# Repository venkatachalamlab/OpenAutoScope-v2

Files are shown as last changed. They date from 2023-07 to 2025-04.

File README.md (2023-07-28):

# OpenAutoScope2.0

<div style="display: flex; justify-content: center;">
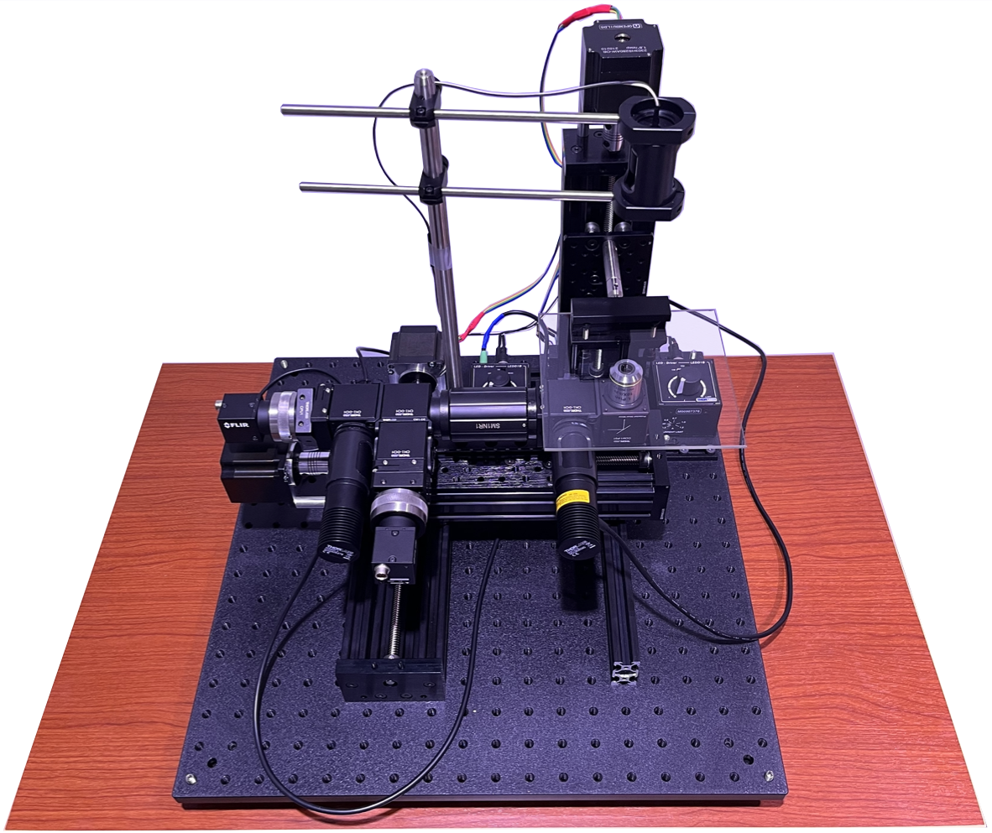
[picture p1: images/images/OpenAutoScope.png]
    
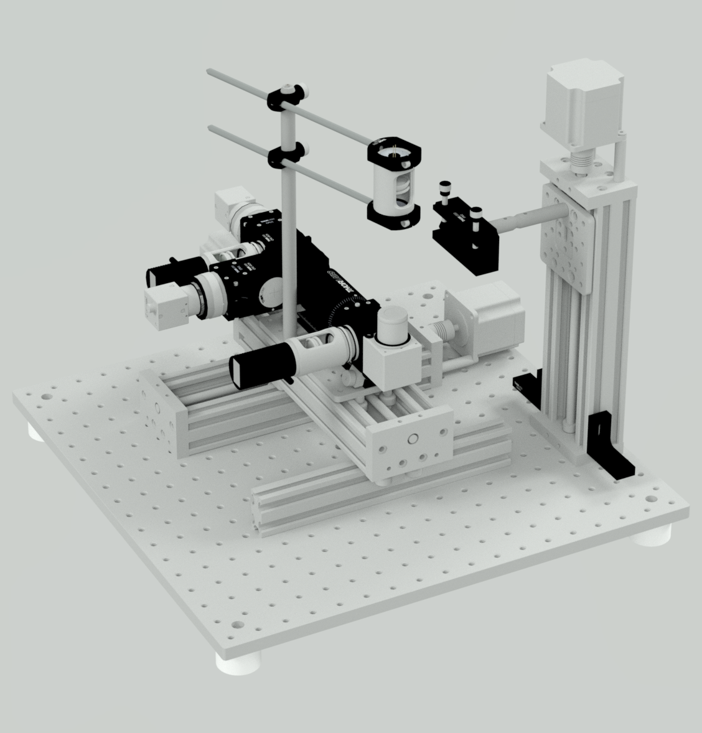
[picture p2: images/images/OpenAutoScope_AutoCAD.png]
    
</div>

# About

The OpenAutoScope is a compact dual-channel microscope engineered to enable precise tracking of single nematodes  (_C. elegans_) and facilitate optogenetic experiments. This imaging system allows recording behavior and dynamic fluorescence (e.g. GCaMP) from a small number of well-separated cells while simultaneously delivering non-targetted light stimulation.

# Hardware Design
OpenAutoScope2.0 houses optical components in a compact design, mounted on an xy motorized stage. A tracking system ensures the sample remains stationary in the xy-plane while permitting movement in the z direction. There are three distinct light paths: an IR path for behavior, a 595nm path for optogenetic stimulation, and a 470nm path for fluorescent imaging in a GFP channel. To simultaneously focus on the sample for both behavior and GFP imaging, we have included an adjustable tube lens and a separate 5mm travel range for each camera.

<p align="center">
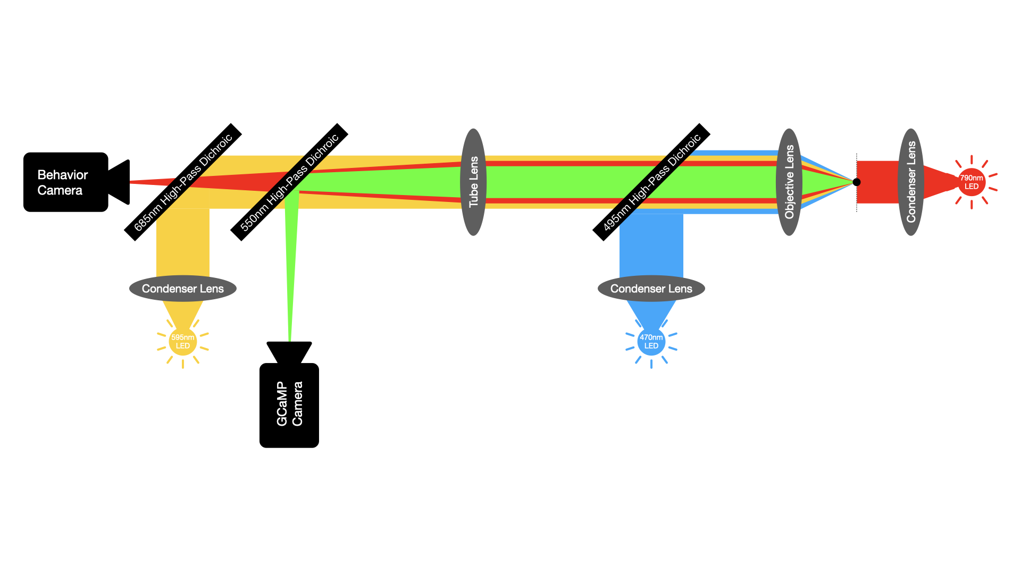
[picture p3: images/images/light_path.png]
  
</p>

# Software Design
OpenAutoScope2.0 comes with an open-source software primarily written in Python. Its architecture comprises multiple devices, each responsible for controlling a specific hardware component or performing a designated task. Communication between these devices occurs through the ZeroMQ messaging library.

The system utilizes two FLIR cameras for imaging purposes. To interface with these cameras, specific Software Development Kits (SDKs) are required. Detailed instructions for installing and configuring these SDKs are provided in the [installation](documentation/installation.md) section of the software documentation.

<p align="center">
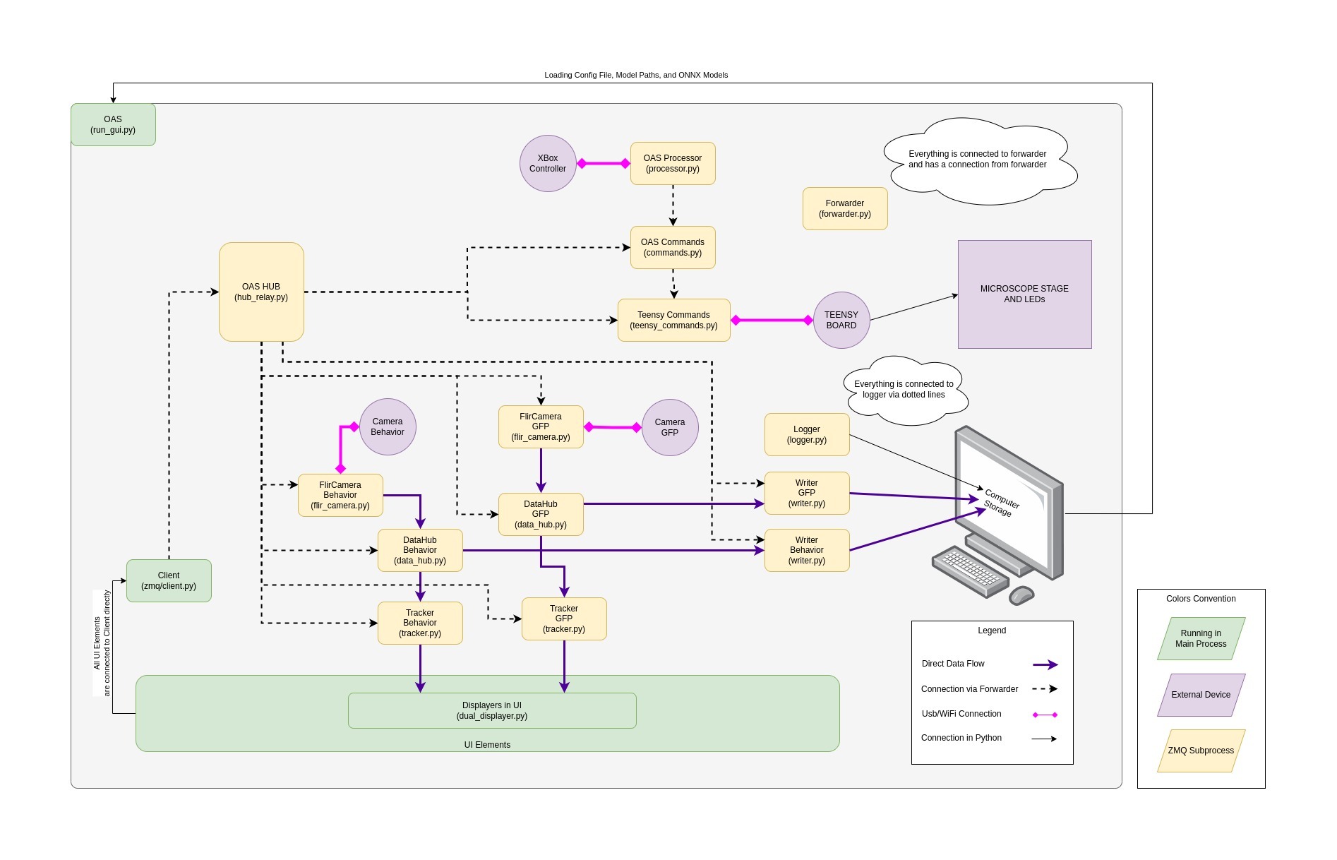
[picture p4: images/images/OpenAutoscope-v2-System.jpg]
  
</p>

# Tracker Design 
To ensure robust and accurate tracking of worms at various developmental stages, we have incorporated a customized version of the [ResNet18](https://arxiv.org/abs/1512.03385) deep CNN. This modified architecture is optimized to minimize inference time while maintaining reliability. Training the network involved utilizing a comprehensive dataset of over 17,000 annotated frames, where the terminal bulb was annotated. In Panel A of the accompanying figure, the architecture of the network is depicted, showing the changes made in the number of planes for each layer. The fully connected (FC) layer has been modified to output two coordinates, representing the y and x positions respectively. In Panel B, the histogram of squared error (SE) losses for the test data is plotted, providing insights into the performance of the network. Additionally, Panels C and D showcase images of worms at the L4 and young adult stages, respectively. In Panel C, the worm is situated on a seeded plate, while in Panel D, it is positioned between the agar pad and the glass (for detailed instructions on sample preparation, refer to [this resource](documentation/sample_preparation.md)). The annotated points are represented by red dots, while the blue circles correspond to the output generated by the trained network.

<p align="center">
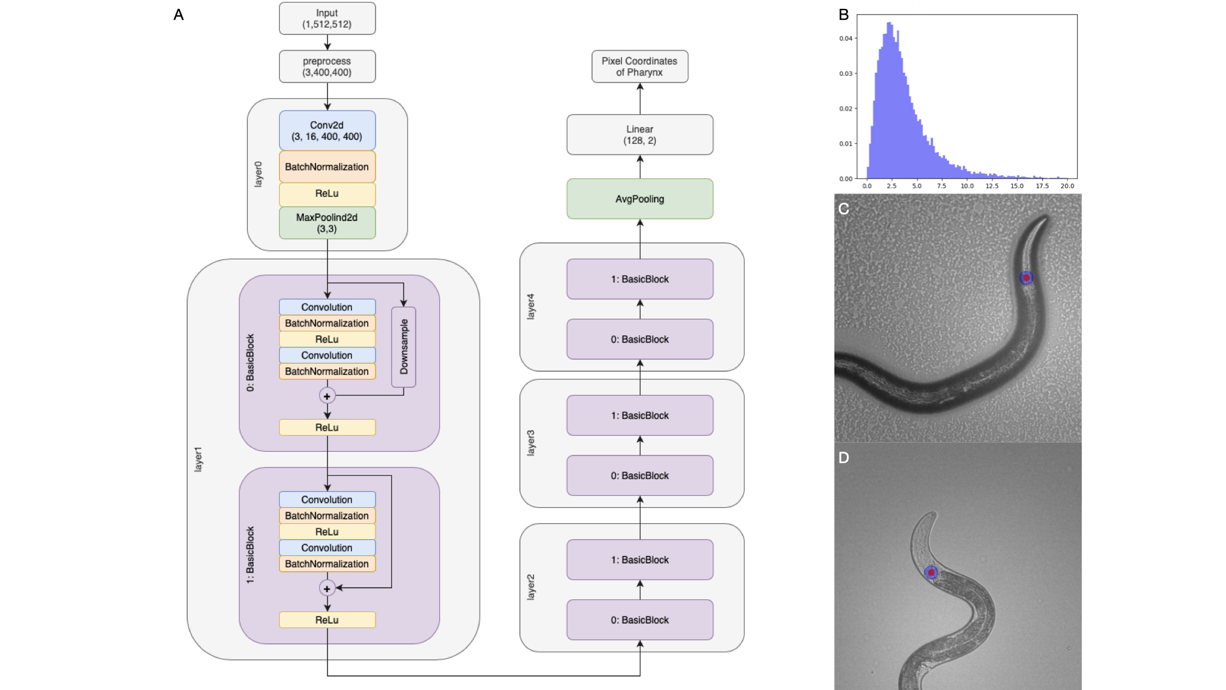
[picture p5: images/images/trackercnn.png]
  
</p>

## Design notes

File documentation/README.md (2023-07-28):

This is to navigate to different sections of the documentation for OpenAutoScope2.0. The tutorials provided cover a range of topics including assembling the system,
installing the software, configuring the necessary parameters, performing calibration, preparing samples for optimal results, and conducting imaging sessions on the prepared samples.
You can refer to the specific sections that align with your current needs and requirements.

## [Printed Circuit Board](../pcb)

The manufacturing of the printed circuit board (PCB) typically requires a certain amount of time. There are multiple vendors available, both within and outside the US, that handle PCB production. We used EasyEDA for designing the PCB and ordering it, including the soldered components.

## [Software Installation](installation.md)
The git repository contains all the software codes for the system, primarily written in Python programming language. To ensure the hardware components, such as the Cameras and Teensy board, function properly, specific Software Development Kits (SDKs) are needed. This file provides a comprehensive, step-by-step guide on installing all the necessary packages, libraries, and SDKs for running the system effectively.

## [Hardware Assembly](https://drive.google.com/file/d/1PnN88vxZwhIJeRHgJQa5Ft3MLd5eSH1t/view?usp=share_link)
The provided pdf file serves as a comprehensive construction manual for the OpenAutoScope 2.0 system. It offers a detailed, step-by-step guide for assembling the system. The list of all the necessary parts required for the assembly can be found [here](../parts/parts.pdf). Towards the final stages of the assembly process, the SpinView application is utilized to align the cameras accurately. For more information on installing the SpinView application, refer to the [installation](installation.md) section.

## [Graphical User Interface (GUI)](gui.md)
This document provides an explanation of the various elements present in the graphical user interface (GUI) and their respective functions.
It is assumed that you have already assembled the system before proceeding to this stage.

## [Parameters](parameters.md)
Within this file, you will find the definitions for parameters in the [configuration file](../configs.json) as well as various other components of the system.

## [Calibrations](calibration.md) 
At this stage, with the hardware assembly completed and the software installed, you are ready to run the system and utilize the graphical user interface. However, it is important to note that certain devices may require calibration, and the cameras need to be aligned to ensure simultaneous focus and image alignment. This guide shows you how to perform the necessary steps.

## [Sample Preparation](sample_preparation.md)
The purpose of the protocol is to ensure optimal performance of the tracking algorithm by emphasizing the importance of sample preparation. To achieve precise z tracking during imaging and effectively image single neurons, it is recommended to prepare the sample on glass. For improved tracking accuracy, it is advised to prepare agar plates with a low peptone percentage and seed them with a small amount of OP50 close to the experiment's execution, minimizing food residues in the recordings. Additionally, creating thin agar plates and utilizing agarose or noble agar enhances sample transparency, thereby increasing the signal-to-noise ratio in the recordings.

## [Motion Control With The Xbox Controller](xbox_controller.md)
This explains how you can utilize an Xbox controller to easily move the stage and find the sample and focus on it.

## [How to run an imaging session](imaging_session.md)
This is an example flow for an imaging session with OpenAutoScope 2.0:

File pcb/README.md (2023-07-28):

# Printed Circuit Board

Inside this folder, you will find the Gerber files for the printed circuit board (PCB).
These files contain the necessary data for manufacturing the PCB, including the copper traces, drill holes, and component placements.

## How to Order PCB

To order the PCB, please visit [EasyEDA](https://docs.easyeda.com/en/PCB/Order-PCB), the platform we used for designing the PCB. EasyEDA allows you to upload
the Gerber files and provides options for customizing your order, such as choosing the PCB material, thickness, and quantity.

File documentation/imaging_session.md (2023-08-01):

Here is an example flow for running an imaging session:

1- Begin by following the [sample preparation protocol](sample_preparation.md) to prepare your imaging sample.  
2- Open a command prompt and enter `activate oas && oas` to run the GUI.  
3- Select the directory where you want to save the data from the imaging session.  
4- If you intend to employ the z interpolation method for tracking, simply mark the checkbox for 'z interpolation tracking' on the GUI. Then, locate three designated points on the agar surface and adjust the stage's position in the z direction to focus on each of these points. Once focused on a point, press the corresponding 'set point i' button on the GUI, where 'i' represents the index of the point.  
5- Utilize the buttons on the graphical user interface (GUI) or the Xbox controller to locate and position the worm within the field of view.  
6- Choose the appropriate x-y tracking model for your experiment.  
7- Confirm that the tracker is detecting the worm correctly (left displayer on the GUI).  
8- Start the tracking. The system will continuously update the tracked data as the imaging session progresses.  
9- Begin the recording of the imaging session to capture the data.

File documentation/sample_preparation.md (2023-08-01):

# Protocol: Sample Preparation

## Objective
The objective of this protocol is to prepare samples for single worm tracking using OpenAutoScope2.0. The tracking accuracy heavily relies on the cleanliness of the samples. This protocol demonstrates two different methods of sample preparation: on the plate and on the glass, utilizing NGM plates prepared on 10cm petri dishes.

For imaging durations of a few minutes, an unseeded plate can be used. However, for longer imaging sessions, starved animals may exhibit different behavior, necessitating the use of seeded plates. To minimize interference with tracking, NGM plates with reduced Peptone content are employed. These plates are seeded with a thin lawn of OP-50 bacteria hours before the experiment. Although the trace of the animal on the seeded plates can potentially interfere with tracking, the small amount of food provided is sufficient for the survival of the single animal being tracked.

Furthermore, to minimize background noise in the GFP channel, agarose or noble agar can be used to prepare the plates. These materials increase the transparency of the agar pads, thereby reducing background noise and enhancing image quality.

## Materials

- 10cm NGM plates (low in peptone, made with agarose or noble agar)
- 5"x5" Glass (part of the OpenAutoScope2.0 setup)
- Scalpel
- Sharpie
- OP-50 in LB
- 200ul pipette
- Cell Spreader

<div style="display: flex; justify-content: center;">
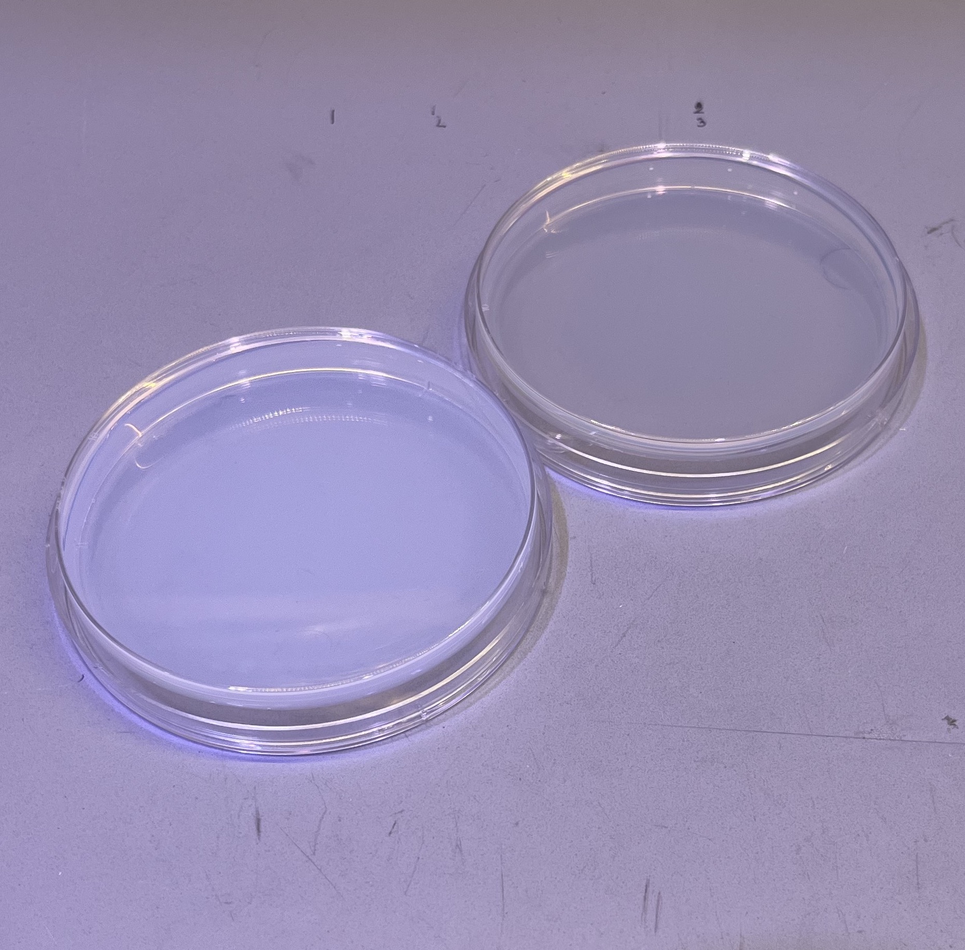
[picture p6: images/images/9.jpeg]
    
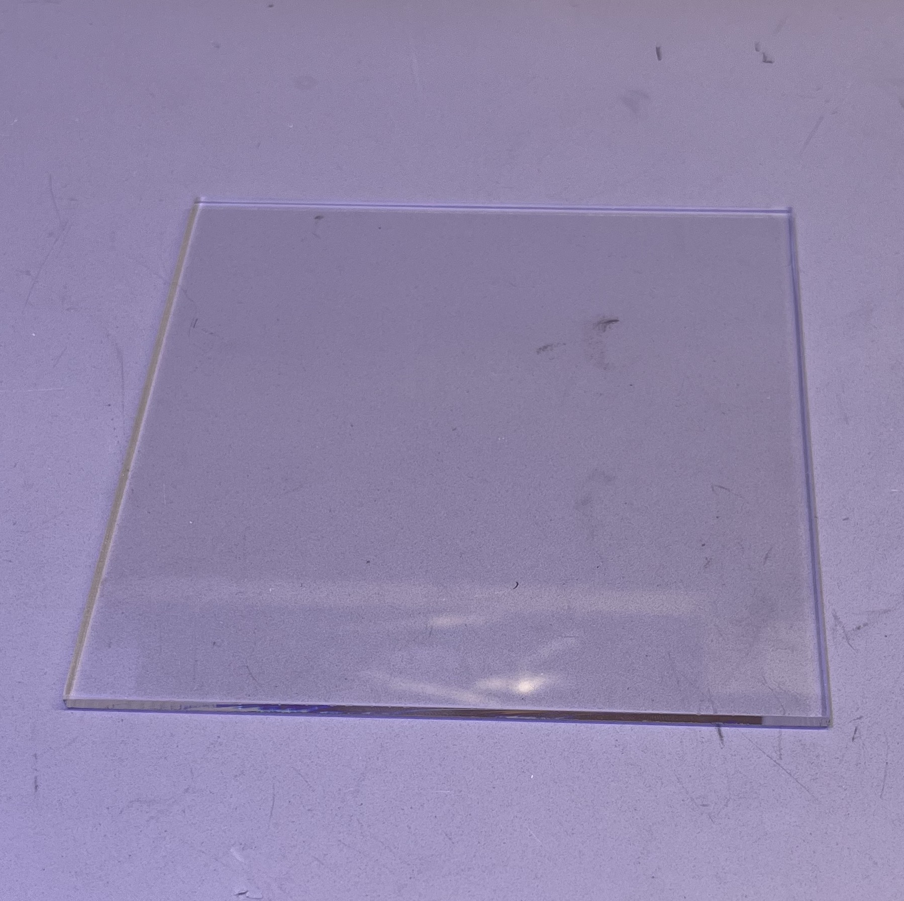
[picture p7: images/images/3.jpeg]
    
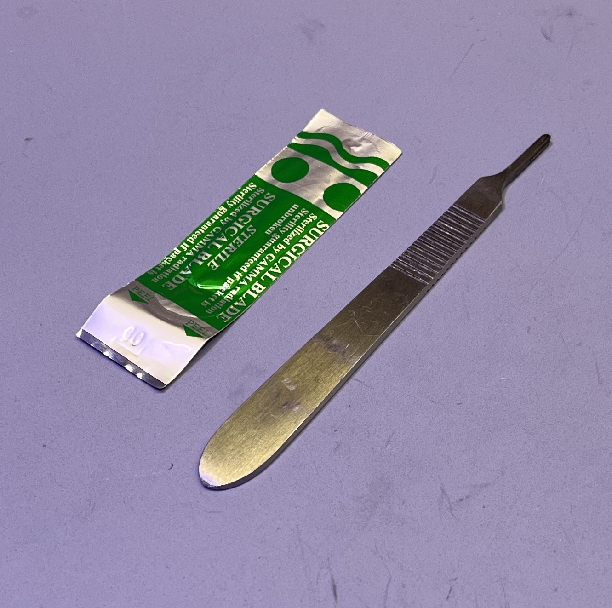
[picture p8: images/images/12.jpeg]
    
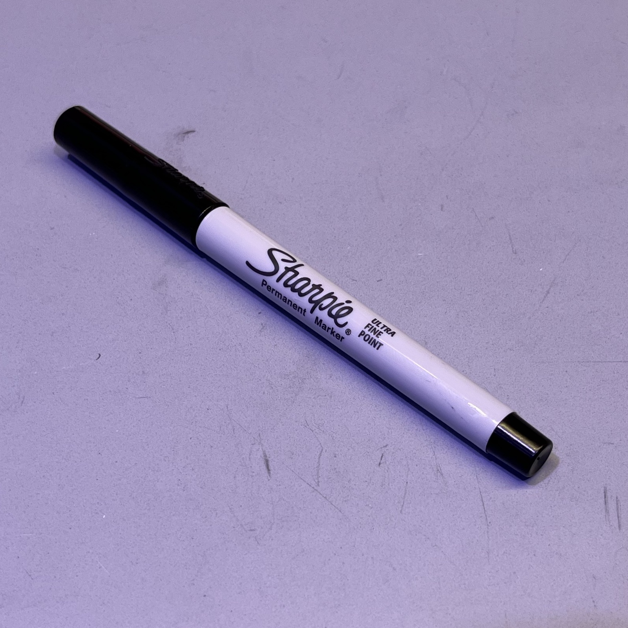
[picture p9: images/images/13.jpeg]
    
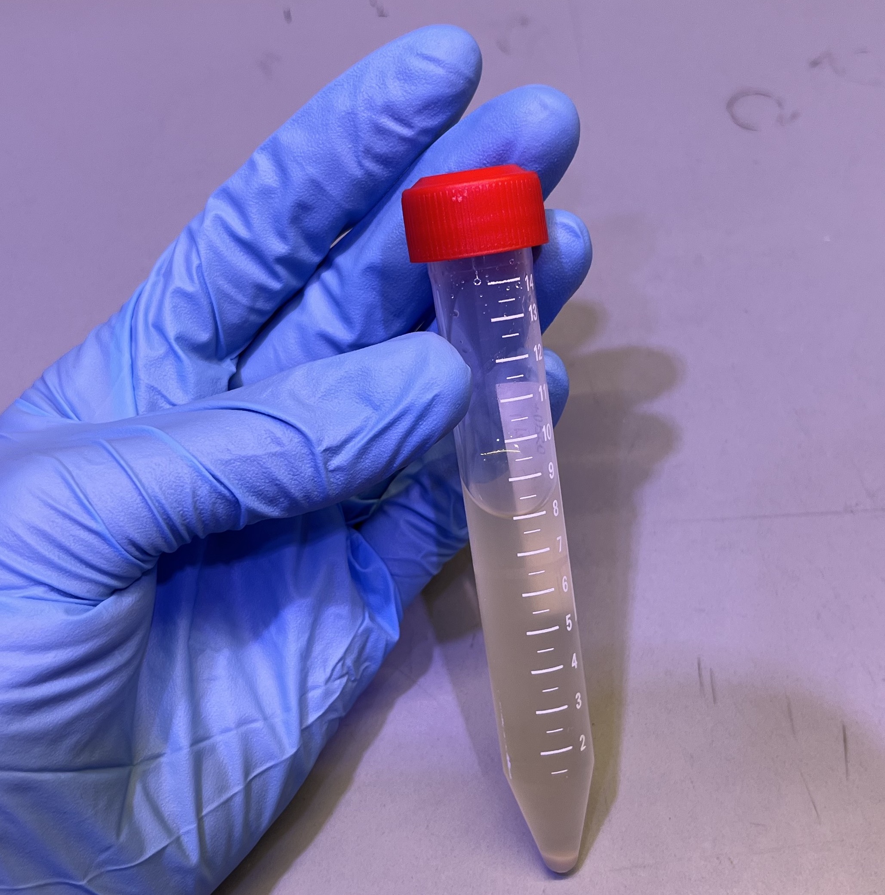
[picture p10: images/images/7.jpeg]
    
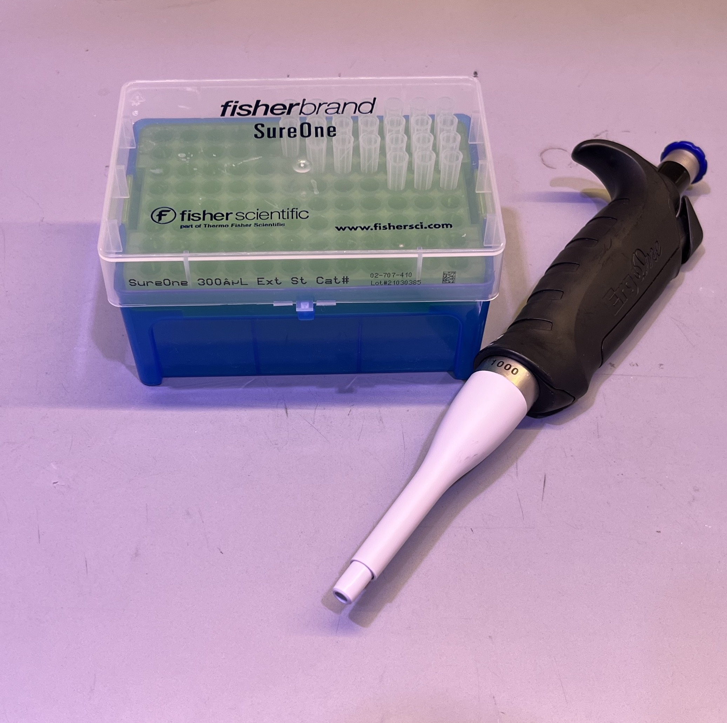
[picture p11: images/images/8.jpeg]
    
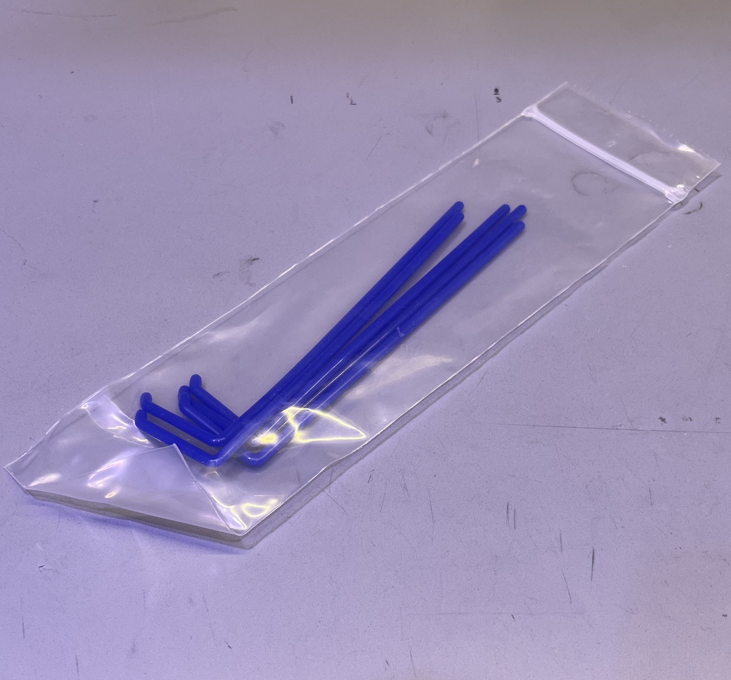
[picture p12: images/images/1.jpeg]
    
</div>

## Seeding Procedure (for longer imaging sessions):
- Dispense 200 μl of OP-50 bacteria in LB onto the center of the 10cm NGM plate.
- Using a cell spreader or a sterile glass rod, evenly distribute the bacterial solution across the surface of the plate.
- Allow the plate to sit undisturbed for 2-3 hours, or until the bacterial solution has dried completely.
- To ensure precise z-tracking, mark three distinct points on the agar plate surface, each spaced more than 2cm apart. These reference marks can be created using either copper powder or copper sulfate. Worms tend to avoid copper, making it an effective means to encourage them to remain in the central area of the plate. Alternatively, you may utilize a worm pick to leave a mark on the plate.

Please ensure that all materials used for dispensing and spreading the bacteria are sterile to maintain the cleanliness of the samples.  

<div style="display: flex; justify-content: center;">
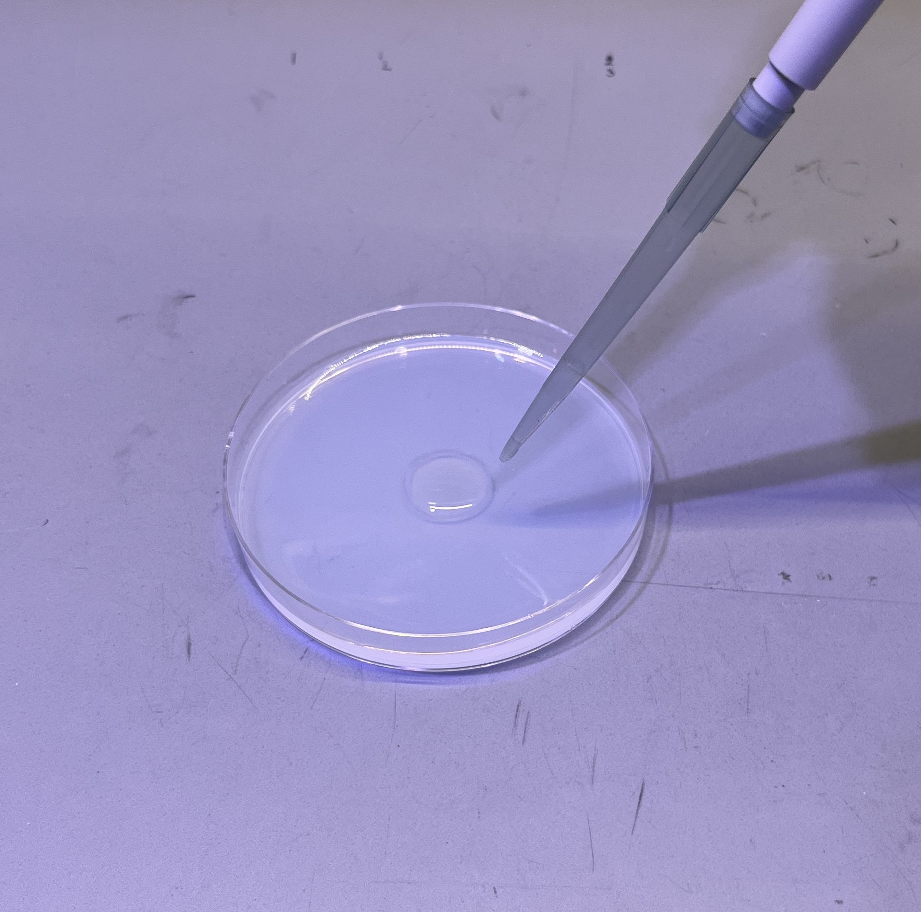
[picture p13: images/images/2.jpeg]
    
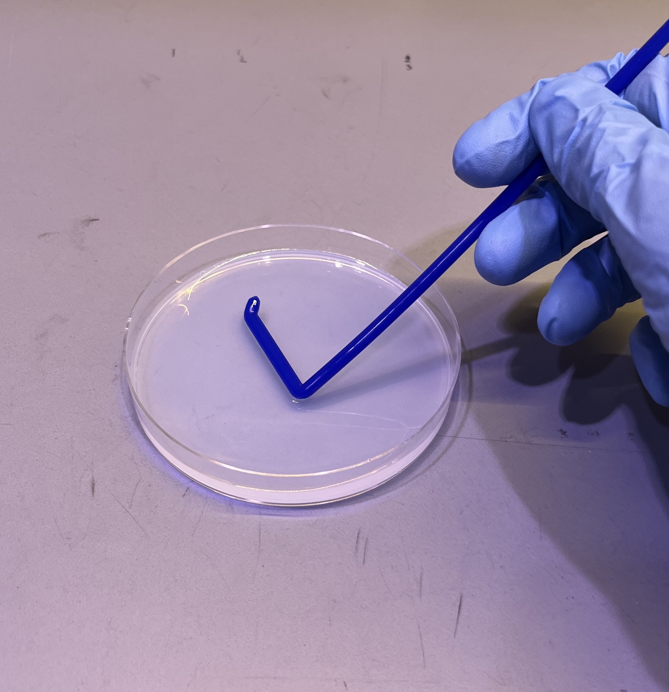
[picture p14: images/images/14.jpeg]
    
</div>

## Procedure
1- Sample Preparation on the Plate:

 - Pick a worm of interest using a worm pick or platinum wire and transfer it onto the center of the NGM plate.
 - Gently tap the worm pick or platinum wire to encourage the worm to crawl onto the agar surface.
 - Place the NGM plate upside down on a 5"x5" glass slide, ensuring that the surface of the agar plate is facing the objective.

2- Sample Preparation on Glass:  
Please note that this approach may impact the worms' natural movement. Only utilize this method if partial immobilization of the worms does not pose any issues for your specific experiment.
 - Pick a worm of interest using a worm pick or platinum wire and transfer it onto the center of the NGM plate.
 - Use a scalpel to carefully cut the agar around the worm, creating a large rectangle shape with dimensions of approximately 2"x2".
 - Use a scalpel to help lift the agar rectangle (remove the pieces close to the walls of the plate to make it easier to lift the agar pad).
 - Place the rectangular agar pad on the clean 5"x5" glass, ensuring that the worm is trapped between the glass and the agar pad. Carefully roll the agar pad onto the glass to ensure there are no air bubbles trapped between the glass and the agar pad.  
   Note: Ensure that the glass is clean and free from any debris or contaminants.
 - Use a sharpie or marker to mark at least 3 corners of the agar pad on the glass. These marks will be used by OpenAutoScope to define the plane of the glass for precise z-tracking during imaging.  

  <div style="display: flex; justify-content: center;">
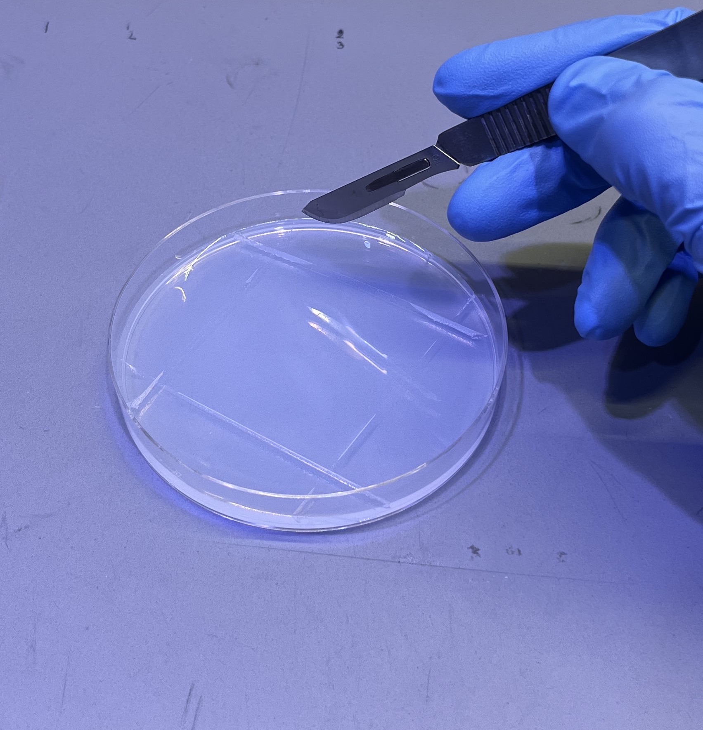
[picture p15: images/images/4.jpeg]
    
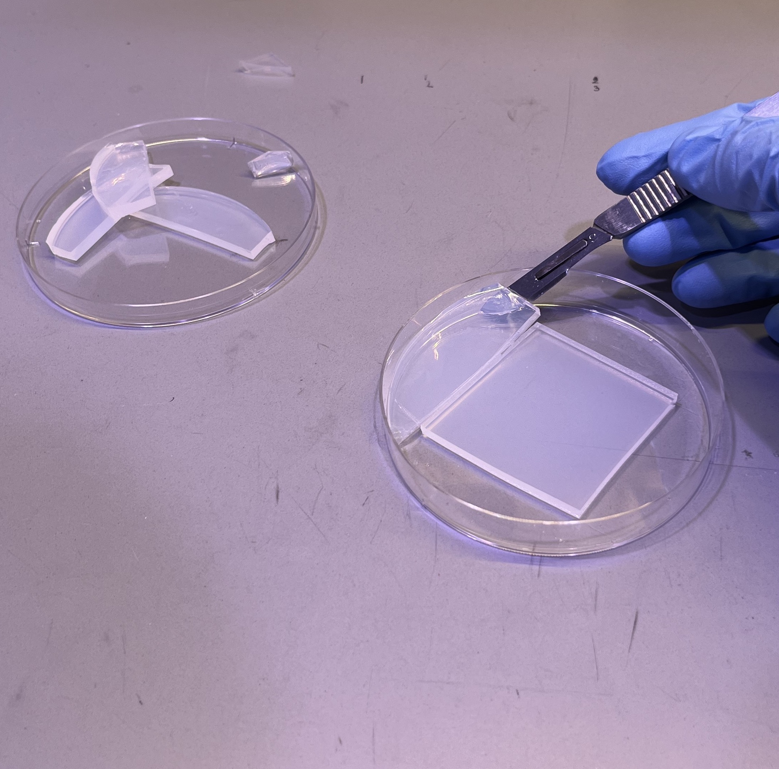
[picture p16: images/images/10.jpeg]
    
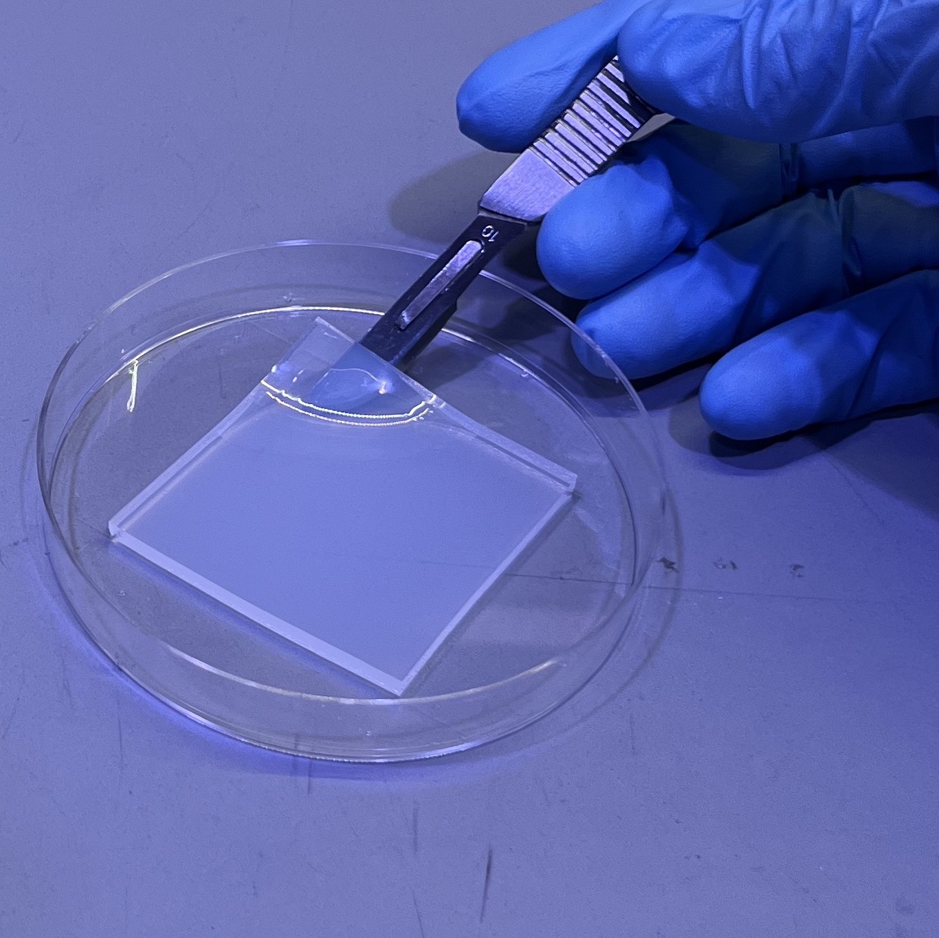
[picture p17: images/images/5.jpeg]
    
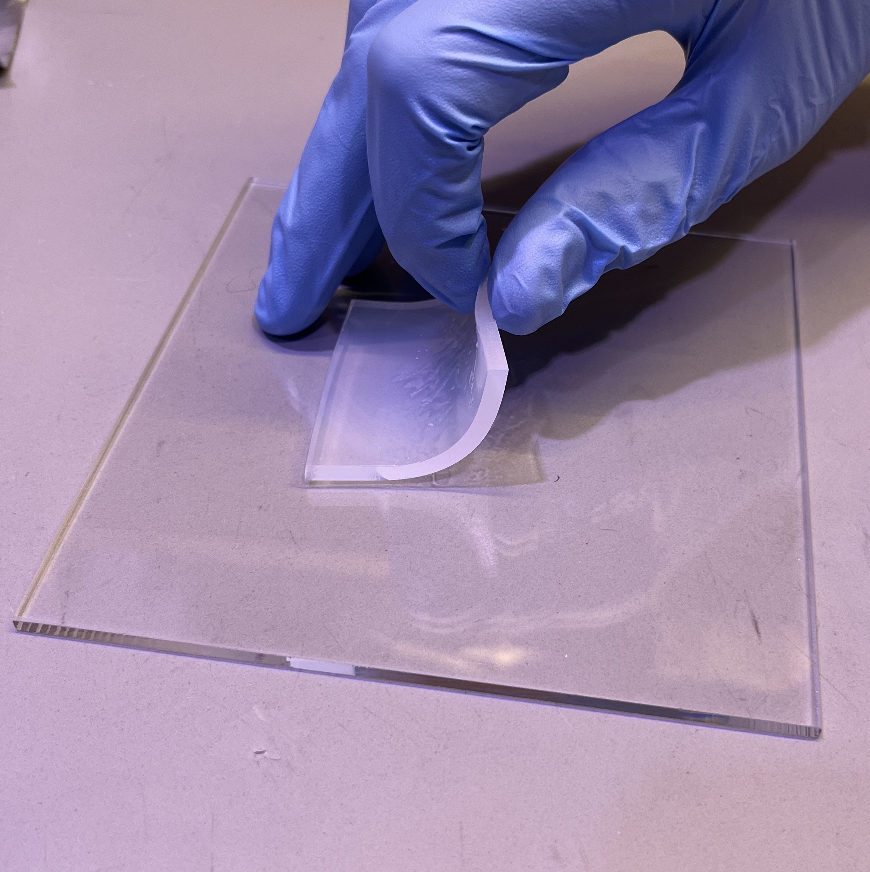
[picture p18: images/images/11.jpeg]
    
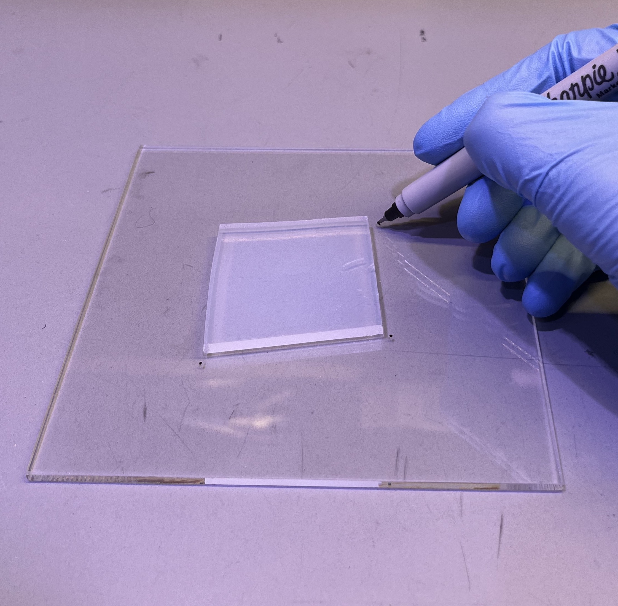
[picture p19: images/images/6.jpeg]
    
  </div>

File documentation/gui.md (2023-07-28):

# Graphical User Interface (GUI)

If you have successfully completed the previous steps, you can run the system by entering the following command into a command prompt window, regardless of the current directory:
```
activate oas && oas
```
The software's graphical user interface (GUI) resembles the image displayed below.
  
<p align="center">
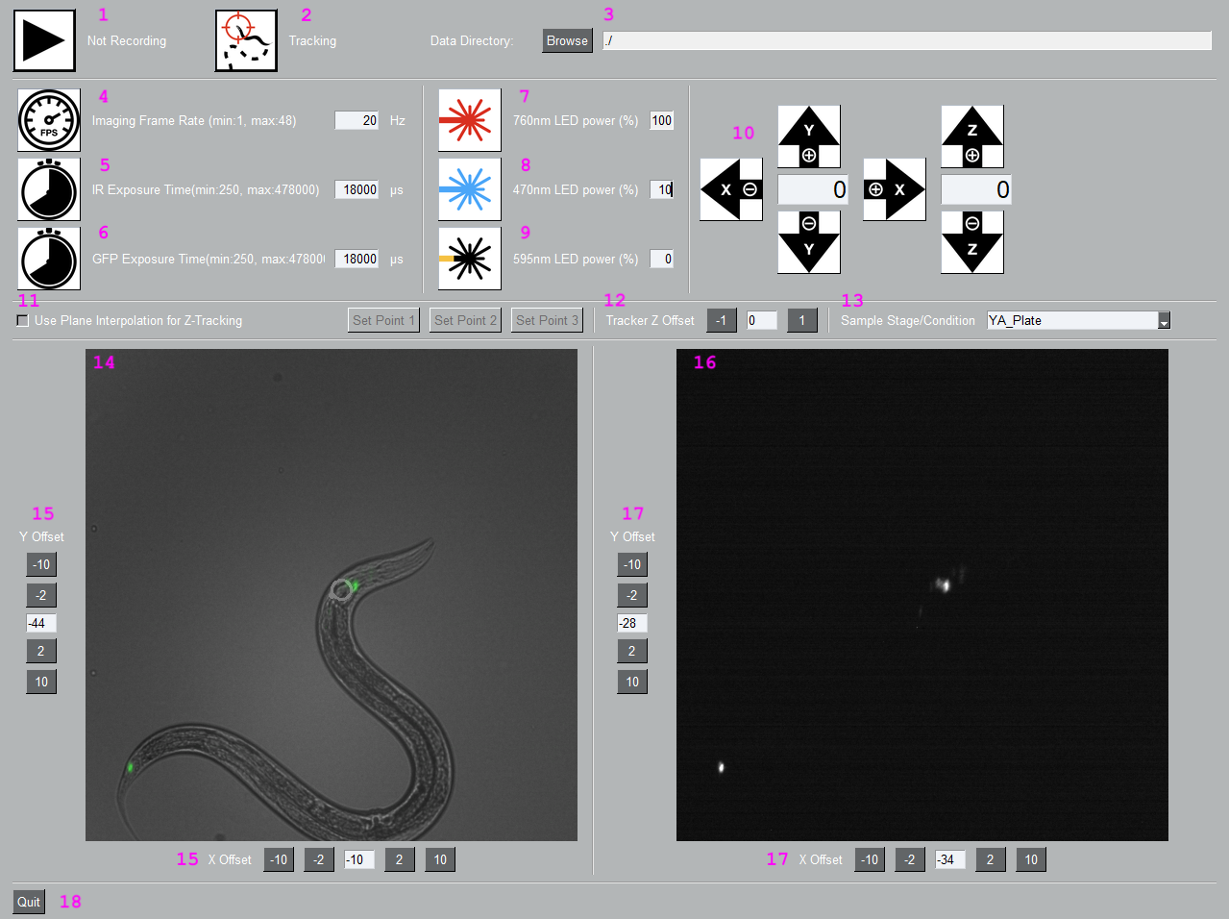
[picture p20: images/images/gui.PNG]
  
</p>

### 1: Recorder Toggle
This button serves as a toggle for recording. The current recording status, indicating whether recording is active or not, is displayed next to the button.
Once the recording begins, two HDF files and a log file are generated at the location specified in __Data Directory__.

### 2: Tracker Toggle
This button functions as a toggle for tracking. The tracking method is determined by __Plane Interpolation Z Tracking__,
__Tracking's Z Offset__, and __Tracking Mode__.
The current tracking status, indicating whether tracking is active or not, is displayed next to the button.
### 3: Data Directory
Here, you can specify the location where the log file and data are saved. It is recommended to create separate folders for each recording session.
### 4: Imaging Frame Rate
You can set the imaging frame rate here. The minimum and maximum allowed values are indicated in parentheses. For most behavioral experiments, a frame rate of 20Hz is sufficient.
Keep in mind that higher frame rates will increase the size of the recorded data, and certain tracking methods may require more computational resources,
potentially leading to tracking issues.
### 5: GFP Camera Exposure Time
This parameter determines the exposure time for the camera recording the behavior (left displayer). The minimum and maximum values depend on the current frame rate
__Imaging Frame Rate__. Setting a high exposure time can lead to the loss of features due to saturation.
### 6: Behavior Camera Exposure Time
This parameter controls the exposure time for the camera recording the GFP signal (right displayer). The minimum and maximum values depend on the current frame rate
__Imaging Frame Rate__. It is important to avoid increasing this parameter excessively to prevent camera saturation, which can compromise the extraction of meaningful GCaMP signals.
### 7: IR LED Toggle
This button serves as a toggle for the IR LED, which acts as the light source for behavior recording.
The LED can only be turned on or off; therefore, the intensity is fixed at 100 and cannot be adjusted.
### 8: 470nm LED
This button functions as a toggle for the 470nm LED, serving as the light source for the green fluorescent proteins. The LED can be switched on or off,
and the intensity can be adjusted from 0 to 100 percent. Setting the intensity to 100 percent corresponds to passing the maximum allowed current to the LED.
### 9: 595nm LED
This button functions as a toggle for the 595nm LED, serving as the light source for specific optogenetic experiments. The LED can be switched on or off,
and the intensity can be adjusted from 0 to 100 percent. Setting the intensity to 100 percent corresponds to passing the maximum allowed current to the LED.
### 10: Motion Control
These six buttons enable you to move the stage in the X, Y, and Z directions. The velocity for the X and Y directions is the same but can be adjusted
independently from the velocity of the Z direction. Pressing and holding a button initiates motion in the desired direction, and releasing the button stops the stage's movement.
### 11: Plane Interpolation Z Tracking
This mode is designed for precise Z tracking. To utilize this mode, the sample needs to be prepared on the surface of the glass
(learn more about [sample preparation](sample_preparation.md)). Three points on the glass surface should be marked (using a sharpie, for example).
If the user chooses to use this tracking mode, they should manually adjust the motor in the X, Y, and Z directions to focus on each marked point and then press
the 'Set Point' button. These three points define the plane of the glass surface and will be used to maintain the Z position consistently on this plane.
### 12: Tracking's Z Offset
In case interpolation method is utilized for Z tracking, there's a chance that the neurons or fluorescent elements in the sample might be situated at a different Z position than the target being tracked via the behavior channel. This parameter offers the flexibility to designate an offset, enabling focus on the elements of interest within the GFP channel, even if they're placed at a Z position different from the predicted Z (the result given by the Z tracking algorithm).
### 13: Tracking Mode
There are various tracking algorithms available for capturing motion in the x-y plane. The appropriate method to be used depends on factors such as the magnification of the
objective, imaging conditions (learn more about [sample preparation](sample_preparation.md)), and the developmental stage of the animal (L1, L2, L3, L4, YA). In this section,
you can specify the tracking method to be utilized based on the requirements of your experiment.
### 14: Behavior Displayer
This displays the frames overlaid from the behavior channel and the GFP channel. Before overlaying, a background subtraction is applied to the frame from the GFP channel.
To learn more about how to adjust the level of background subtraction, refer to the [parameters](parameters.md) in the configuration file.The white circle represents the output of the tracking algorithm. It is advised to initiate tracking only if the output aligns with your expectations.
### 15: Behavior Camera Cropping Offset
The displayed images are cropped from the full field of view. These parameters determine the deviation from the center of the full field of view, ensuring alignment between
the images from the two channels. After finding the optimal x and y offset pair, you can enter them in the configuration file. Depending on your system, these parameters may
require periodic adjustments to maintain accurate alignment.
### 16: GFP Dispalyer
This displays the frame from the GFP channel. The presence of high levels of background noise can be attributed to two main factors: poor sample preparation and/or high LED power.
### 17: GFP Camera Cropping Offset
The displayed images are cropped from the full field of view, and these parameters control the deviation from the center of the full field of view. Their purpose is to achieve
alignment between the images from the two channels, as described in __Behavior Camera Cropping Offset__. Depending on the sensor size, it may be necessary to adjust the offset in the GFP camera instead
of changing it in the behavior camera in the opposite direction for one particular axis.
### 18: Quit
This closes the software and, ensures that all open files are properly closed before shutting down the system.

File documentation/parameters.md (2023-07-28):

Presented below is a comprehensive list of parameters that you will encounter throughout the assembly, calibration, and utilization of OpenAutoScope 2.0. Familiarizing yourself with these parameters will greatly assist you in maximizing the system's performance capabilities.

### Camera Serial Number
This is a dual-channel system designed for simultaneous behavior recording and GCaMP recording. Essentially, this system utilizes two separate cameras, each positioned in a distinct light path. The camera located further back specifically captures light that passes through all optical components. Due to the implementation of high-pass dichroic mirrors, this camera primarily collects light with longer wavelengths. As a result, it effectively captures infrared (IR) light, which is utilized as the light source for behavior recording. This camera is referred to as the "behavior camera." On the other hand, the second camera is positioned after the 470nm light source but before the 595nm light source, earning it the designation of the "GCaMP camera". The serial number of each camera is written on its label and is also available when you open the SpinView app, under the 'Devices' panel. Make sure the correct serial numbers for each camera is recorded in the [configuration](../configs.json) file.

### Camera Offset values
The cameras used in this system have a sensor size of 1920 by 1200. To optimize signal quality and reduce file size, we implement a resolution reduction by a factor of 2 and utilize a bin size of two. As a result, the full field of view frame size becomes 960 by 600. However, due to the inherent imperfections of the system's components and the assembly process, there may be offsets in both the x and y directions between the two cameras, despite them receiving signals from the same objective. To ensure perfectly aligned frames, we use a cropped version of the frames. Specifically, from the original 960 by 600 field of view, we crop a 512 by 512 frame. By adjusting the location of these crops, we achieve the desired alignment of frames. The following drawing shows how the full field of view and the offset parameters are related.

<p align="center">
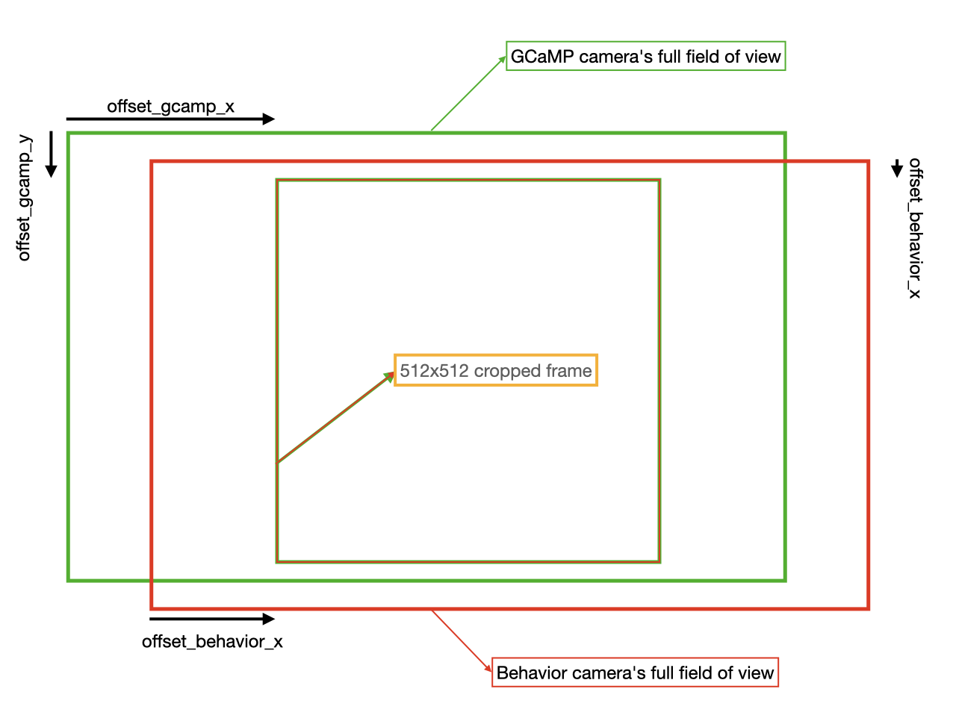
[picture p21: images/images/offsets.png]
  
</p>

### Imaging Frame Rate (framerate)
The frame rate parameter determines the speed at which both cameras capture images. When you initiate the system, the cameras operate at the default frame rate value. However, you have the option to modify this value within the [graphical user interface (GUI)](gui.md). If needed, you can also adjust the default value within the [configuration file](../configs.json). It is worth noting that the frame rate directly impacts the available processing time for online tasks like object detection, which is crucial for tracking. Therefore, it is advisable to run the system at the lowest frame rate that meets the requirements of your specific experiments.

### Exposure time (exposure_gcamp, exposure_behavior)
The exposure time for each camera determines how long the camera sensors collect incoming light. Although both cameras operate at the same frame rate, they have different durations for light capture. It is recommended to use lower frame rates to allow sufficient time for online processing tasks. However, it is essential to limit the exposure time to prevent camera saturation. If small features in bright areas of the images are disappearing or becoming difficult to discern due to high light intensity, it is advisable to decrease the exposure time. The exposure time for each camera can be adjusted within the [graphical user interface (GUI)](gui.md), and the default values can also be modified in the [configuration file](../configs.json).

### Tracking Model
The tracking functionality in this system utilizes a customized variant of ResNet18. By training the network with different datasets, it becomes possible to fine-tune it for various imaging conditions or specific stages. In the [models_path.json](../models_path.json) file, you have the option to include the path to a particular trained model and assign it a key. As a result, within the [graphical user interface (GUI)](gui.md), you will be able to select the desired model using the corresponding assigned key. Alternatively, you can utilize the default trained models provided for tracking.

### Background Subtraction Quantile
The left display in the [graphical user interface (GUI)](gui.md)  shows an overlay of both channels, with the behavior channel displayed in gray and the gcamp channel displayed in green. Due to background noise in the gcamp channel, the overlaid raw data often results in a green hue. To address this, a background subtraction is performed specifically on the green channel. The threshold for this subtraction is determined by the 'q' parameter, which represents the quantile value. By default, 'q' is set to 0.7, but you can adjust this value in the [configuration file](../configs.json). If you prefer to view the raw data overlay without background subtraction, you can set 'q' to 0, resulting in the display of both channels' raw data in the left display.

### X, Y and Z Speed
The motorized stage offers omnidirectional movement through the use of an [Xbox controller](xbox_controller.md). Additionally, we have implemented a GUI feature that allows users to control the stage's movement. In the [configuration file](../configs.json), you will find default speed settings for both the XY direction (xypad-input) and the Z direction (zpad-input). These values can also be modified directly within the [graphical user interface (GUI)](gui.md).

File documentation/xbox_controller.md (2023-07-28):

In this system, we have added the benefits of using an Xbox controller for navigating the system, even though the software itself provides various ways to move the stage
in all directions. The Xbox controller is primarily utilized for motion control, although it is possible to assign additional functions to its buttons if desired.

To adjust the z speed, we can utilize the left and right buttons on the controller. These buttons allow us to modify the speed by a factor of 2, either doubling it or halving it.
The default speed when the software is opened is 1, representing the minimum speed, while the maximum speed achievable is 1024.
This feature grants us flexibility and control over the system's motion, enhancing the overall navigation experience.

Please note the following important information: When pressing the up or down buttons, commands are sent to the motorized stage to initiate motion,
and releasing these buttons sends stop commands. However, it is crucial to be aware that if other commands, such as navigation in the x-y direction,
are immediately sent after releasing the buttons, there is a possibility that the stop command may be ignored. To prevent this issue, it is recommended
to ensure that releasing the up or down buttons is the last action performed, followed by a half-second delay before proceeding with the next action.
This precautionary delay helps to avoid any unintended and continuous movement of the motors in a single direction.

<p align="center">
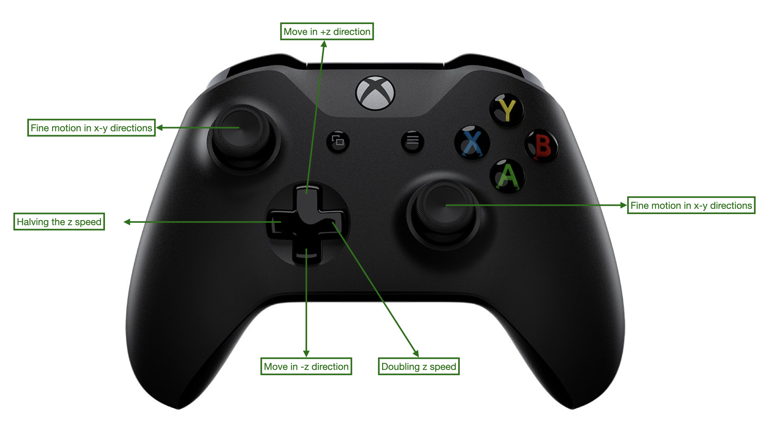
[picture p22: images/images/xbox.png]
  
</p>

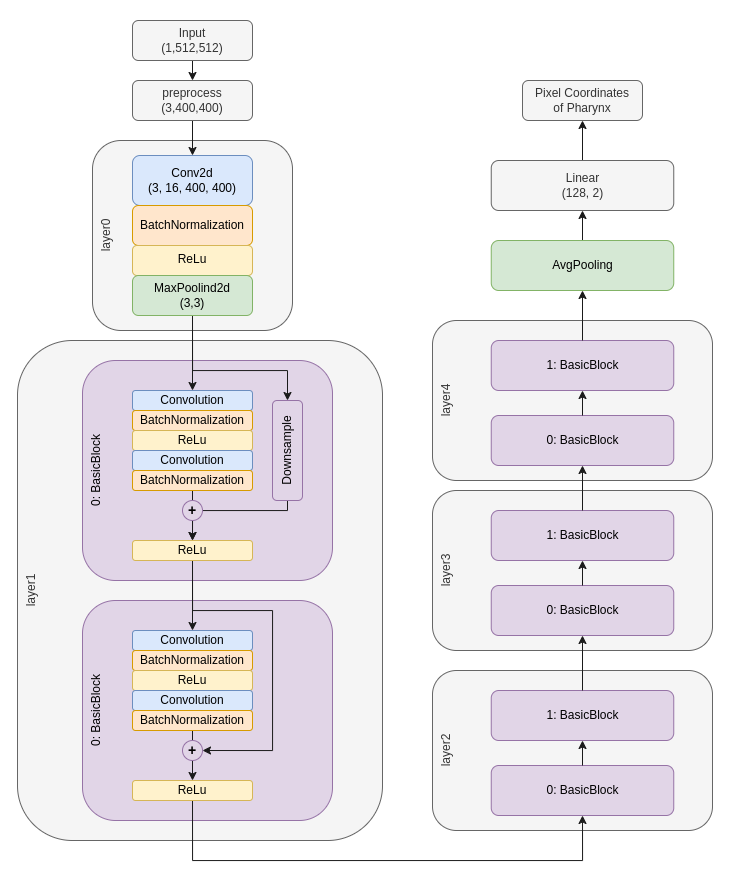
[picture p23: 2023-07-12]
images/images/DepNet16.png

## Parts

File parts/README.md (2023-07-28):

# Parts List
[parts.pdf](parts.pdf) file contains a comprehensive list of all the parts required for building OpenAutoScope2.0. The list includes components such as electronic parts,
mechanical parts, cables, connectors, and any other materials needed for assembly. Please refer to this file to ensure you have all the necessary parts
before proceeding with the construction of OpenAutoScope2.0.

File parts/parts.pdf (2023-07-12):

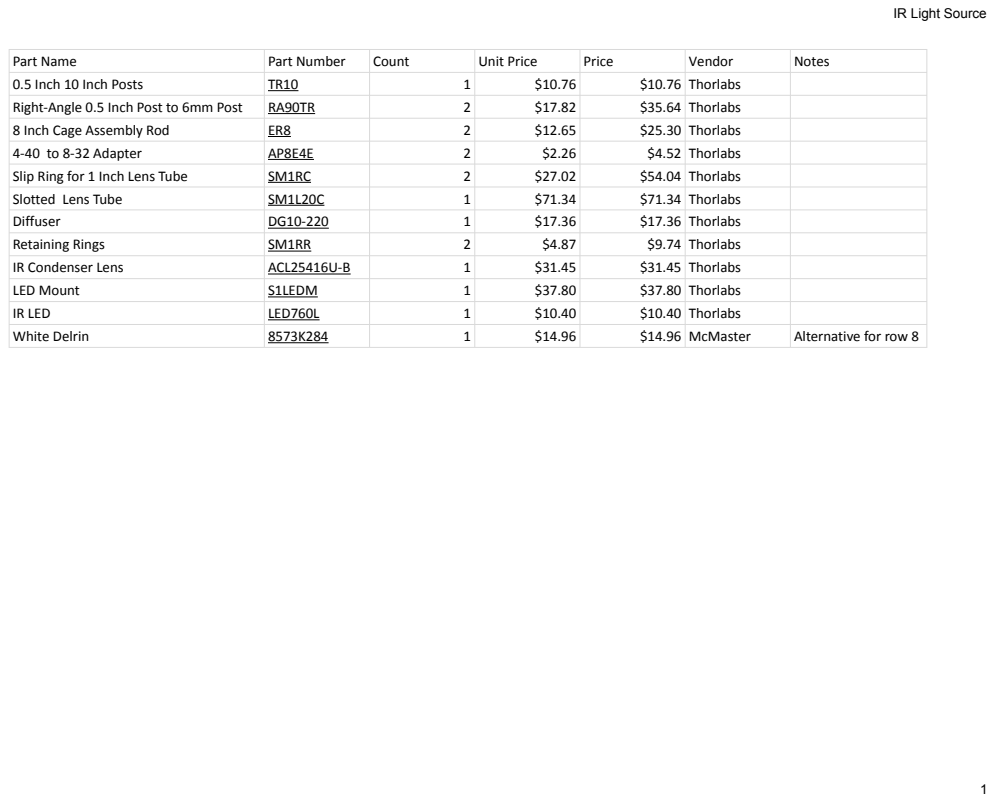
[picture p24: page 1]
Part Name; Part Number; Count; Unit Price; Price; Vendor; Notes; 0.5 Inch 10 Inch Posts; $10.76 Thorlabs; Right-Angle 0.5 Inch Post to 6mm Post; $35.64 Thorlabs; 8 Inch Cage Assembly Rod; $25.30 Thorlabs; 4-40 to 8-32 Adapter; $4.52 Thorlabs; Slip Ring for 1 Inch Lens Tube; $54.04 Thorlabs; Slotted Lens Tube; $71.34 Thorlabs; Diffuser; $17.36 Thorlabs; Retaining Rings; $9.74 Thorlabs; IR Condenser Lens; ACL25416U-B; $31.45 Thorlabs; LED Mount; S1LEDM; $37.80 Thorlabs; IR LED; LED760L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

IR Light Source

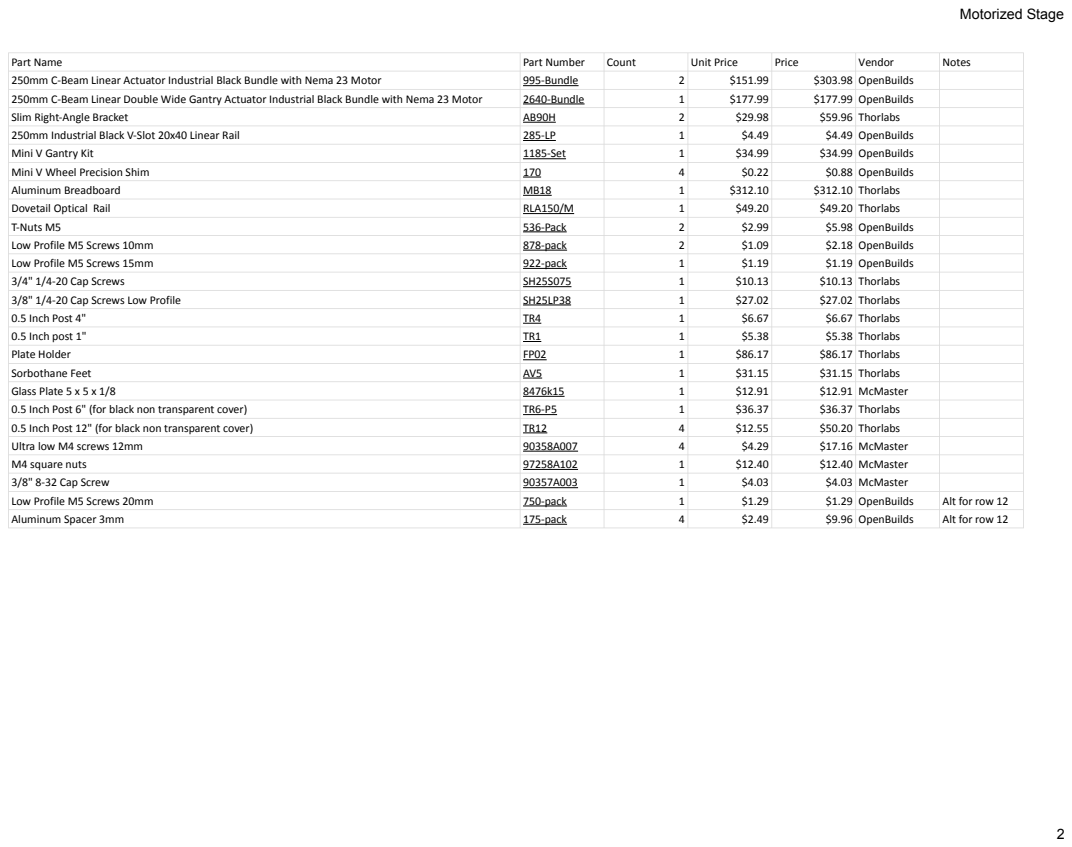
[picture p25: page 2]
Motorized Stage; Part Name; Part Number; Count; Unit Price; Price; Vendor; Notes; 250mm C-Beam Linear Actuator Industrial Black Bundle with Nema 23 Motor; 995-Bundle; $303.98 OpenBuilds; 250mm C-Beam Linear Double Wide Gantry Actuator Industrial Black Bundle with Nema 23 Motor; 2640-Bundle; $177.99 OpenBuilds; Slim Right-Angle Bracket; $59.96 Thorlabs; 250mm Industrial Black V-Slot 20x40 Linear Rail; $4.49 OpenBuilds; Mini V Gantry Kit; 1185-Set; $34.99 OpenBuilds; Mini V Wheel Precision Shim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

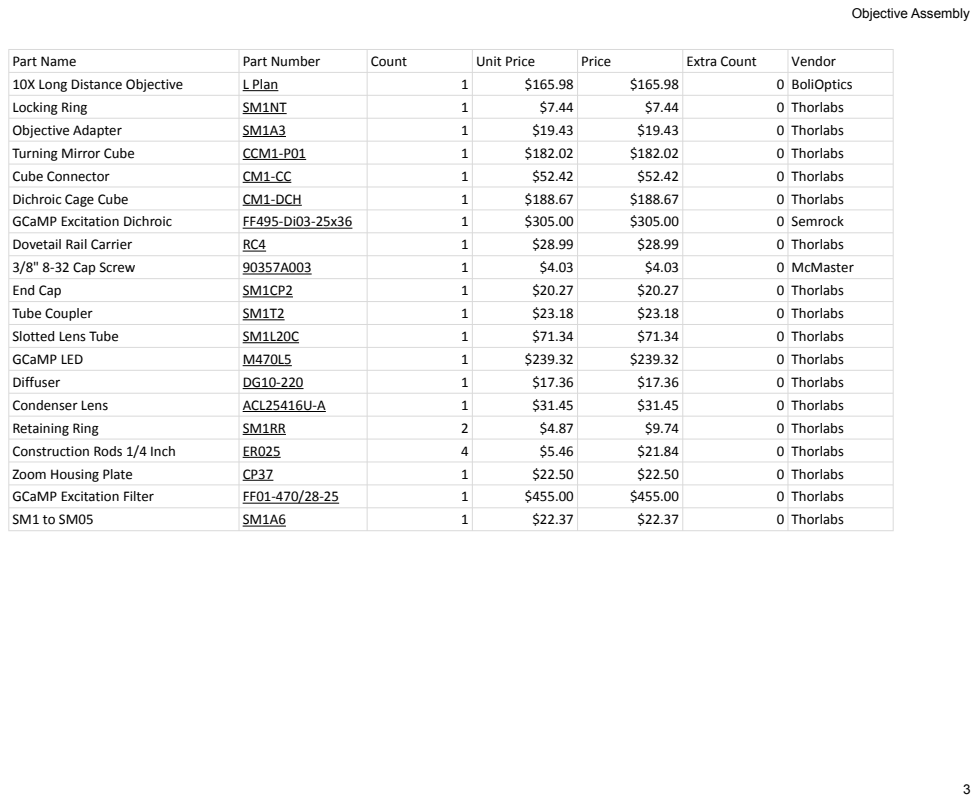
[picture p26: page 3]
Objective Assembly; Part Name; Part Number; Count; Unit Price; Price; Extra Count; Vendor; 10X Long Distance Objective; L Plan; 0 BoliOptics; Locking Ring; 0 Thorlabs; Objective Adapter; Turning Mirror Cube; CCM1-P01; Cube Connector; Dichroic Cage Cube; CM1-DCH; GCaMP Excitation Dichroic; 0 Semrock; Dovetail Rail Carrier; 3/8" 8-32 Cap Screw; 0 McMaster; End Cap; Tube Coupler; Slotted Lens Tube; GCaMP LED; Diffuser; Condenser Lens; ACL25416U-A; Retaining Ring; Construction Rods 1/4 Inch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

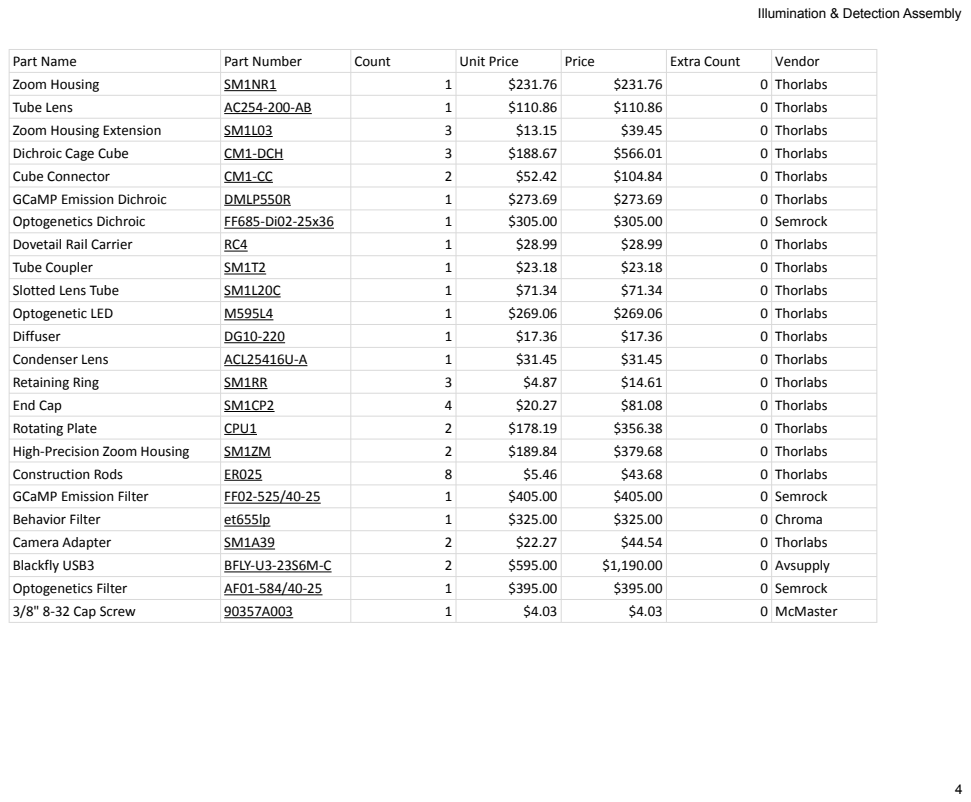
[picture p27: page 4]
Part Name; Part Number; Count; Unit Price; Price; Extra Count; Vendor; Zoom Housing; 0 Thorlabs; Tube Lens; Zoom Housing Extension; Dichroic Cage Cube; CM1-DCH; Cube Connector; GCaMP Emission Dichroic; DMLP550R; Optogenetics Dichroic; 0 Semrock; Dovetail Rail Carrier; Tube Coupler; Slotted Lens Tube; Optogenetic LED; Diffuser; Condenser Lens; ACL25416U-A; Retaining Ring; End Cap; Rotating Plate; CPU1; High-Precision Zoom Housing; Construction Rods; GCaMP Emission Filter; Behavior Filter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

Illumination & Detection Assembly

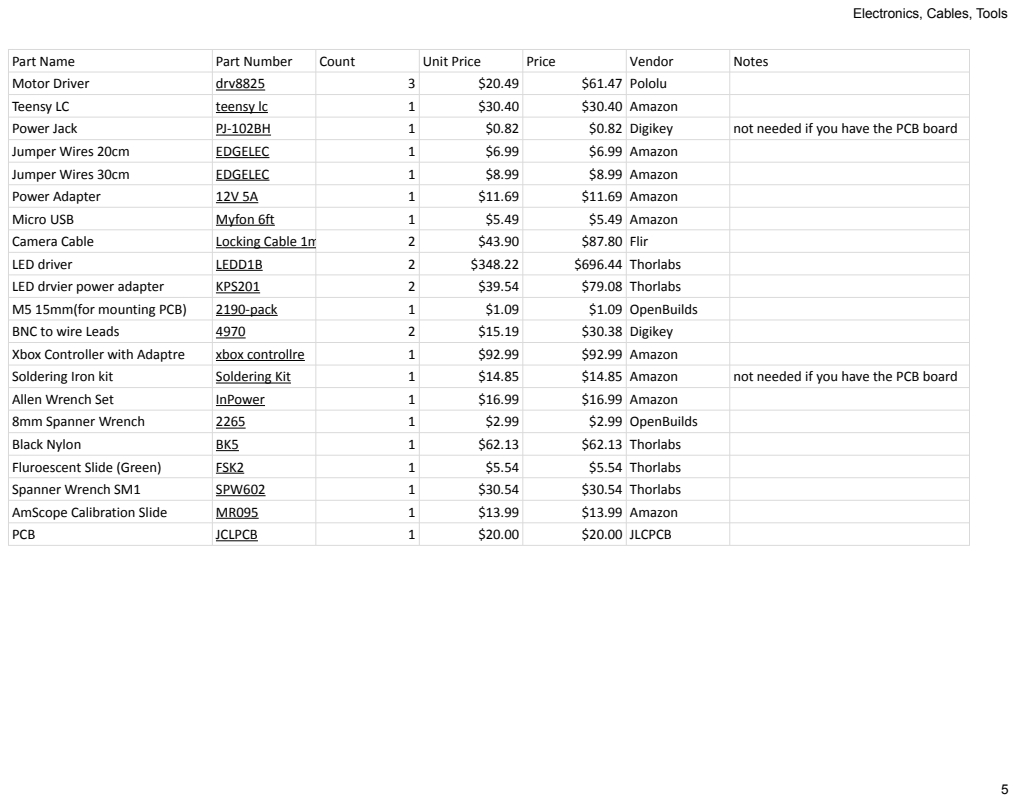
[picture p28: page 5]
Part Name; Part Number; Count; Unit Price; Price; Vendor; Notes; Motor Driver; drv8825; $61.47 Pololu; Teensy LC; teensy lc; $30.40 Amazon; Power Jack; $0.82 Digikey; not needed if you have the PCB board; Jumper Wires 20cm; EDGELEC; $6.99 Amazon; Jumper Wires 30cm; $8.99 Amazon; Power Adapter; $11.69 Amazon; Micro USB; Myfon 6ft; $5.49 Amazon; Camera Cable; Locking Cable 1m; $87.80 Flir; LED driver; LEDD1B; $696.44 Thorlabs; LED drvier power adapter; KPS201; $79.08 Thorlabs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

Electronics, Cables, Tools

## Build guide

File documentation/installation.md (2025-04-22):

# Installation Guide
This file provides a comprehensive guide for the step-by-step installation of all essential software required for OpenAutoScope2.0. It is designed with a blank Windows machine in mind, therefore, if your Windows machine already has certain software components installed, you are welcome to skip those specific steps accordingly.

## Overview
Here are the general steps to follow

- (1) Install required SDK to operate the FlirCameras throught your computer -> install SpinnakerSDK in Development Mode

- (2) Create a python virtual environment to install all requirements there -> install Anaconda

- (3) Install `OAS` along with its requirements inside the python virtual environment -> download from Github and install

- (4) Install ArduinoIDE to edit and upload code to the Teensy controller device -> install ArduinoIDE and configure Teensy Support

- (5) Running `OAS` procedure and testing how it works -> open CMD, activate `oas` environment, run `oas`

It's recommended to install an IDE to help with reading and editing the codes and config files. E.g. [Visual Studio Code](https://code.visualstudio.com/) with [VSCode Python Extension](https://marketplace.visualstudio.com/items?itemName=ms-python.python).

## (0) Create a folder for all files
The `OAS` software and the required-installation-files will be located inside a folder that we will create now.

Create a folder inside the `C` drive called `src`, either through windows `File Explorer` or with the following command in command-line (CMD)
```
if not exist "c:\src" mkdir "c:\src" && cd "c:\src"
```
> Now you should have a folder at this location `c:\src`.

## (1) Spinnaker (SDK and SpinView)
> **Note:** As long as the version of the `SpinnakerSDK.exe` software installed, matches the same `SpinnakerSDK python.whl` version installed, then any version should work in theory! :grin:
> Here we will use the most recent version at the time of writing this guide, `4.2.0.83`, though the tools have been tested with `3.x.x` and `4.0.x` versions as well.

- (1.1) Visit [Teledyne Vision Solutions @ Software Development Kits](https://www.teledynevisionsolutions.com/categories/software/software-development-kits/)

- (1.2) Select "Spinnaker SDK" (they have been changing the links, so maybe this link still works [link](https://www.teledynevisionsolutions.com/products/spinnaker-sdk/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))

> It requires an account to log-in and download. At the time of writing this guide (`2025-04-20`), the account is free to make and proceed with the download.

- (1.3) Download the Spinnaker SDK software appropriate for your operating system.
> In our case, it is `Spinnaker SDK 4.2.0.83 for Windows 64-bit (February 28, 2025)`, and downloaded file name is `SpinnakerSDK_FULL_4.2.0.83_x64.exe`

- (1.4) Also make sure to download the accompanying python file on the same page
> In this case, it is `Spinnaker SDK 4.2.0.83 for Windows 64-bit (February 28, 2025) -> 64-bit Python 3.10`, and downloaded file name is `spinnaker_python-4.2.0.83-cp310-cp310-win_amd64.zip`

- (1.5) Open the `SpinnakerSDK_FULL_4.2.0.83_x64.exe` file and follow on-screen steps to install it.
  Note: between the two options 'Camera Evaluation' and 'Application Development', select 'Application Development'  
  Note: Uncheck 'I will use GigE Cameras'   
- (1.6) Unzip the python sdk zip file `spinnaker_python-4.2.0.83-cp310-cp310-win_amd64.zip` by right-clicking on the downloaded zip folder and clicking on 'Extract All'
> This should create a folder with the following file inside `spinnaker_python-4.2.0.83-cp310-cp310-win_amd64.whl`
- (1.7) Move the `spinnaker_python-4.2.0.83-cp310-cp310-win_amd64.whl` file to `c:\src` folder.

## (2) Install Anaconda
- (2.1) Visit [Anaconda](https://www.anaconda.com) website to download the installer for Windows.
- (2.2) Open the installer and follow the on-screen steps to complete the Anaconda installation.
- (2.3) Find `Anaconda Prompt` and open it, then type the following command and follow the instructions. This make the `conda` command recognizable in CMD.
> conda init

## (3) Install OpenAutoScope2.0
You need the files from `OpenAutoScope2.0` GitHub repository. You can download them as a ZIP file or clone the repository using `git` tool.
Assuming you have either "git cloned" or "downloaded and extracted" the repository files, you should have a folder named `OpenAutoScope-v2` with all the files from the repository.
> If the folder name is different, please rename it to `OpenAutoScope-v2`. Also if you download as a ZIP file, make sure to move the folder inside the extraction folder.
- (3.1) Move the content to the folder `c:\src\OpenAutoScope-v2`, double check that the content of this folder is the same as the files you see online on the repository.
- (3.2) Open windows CMD and run following commands (line by line) to create a new python virtual environment with all required tools
```
cd c:\src\OpenAutoScope-v2
conda env create --file=environment.yml
```
- (3.3) Now a python virtual environment should be created. You need to have it activated in CMD every time you want to install new tools
```
conda activate oas
```
> If the line in CMD starts with `(oas)`, this means the virtual environment is already activated and you don't need to activate it.
- (3.4) Install the `SpinnakerSDK python` wheel file `spinnaker_python-4.2.0.83-cp310-cp310-win_amd64.whl` inside the `oas` environment
```
conda activate oas
cd c:\src
pip install spinnaker_python-4.2.0.83-cp310-cp310-win_amd64.whl
```
- (3.5) Now it's time to install the `oas` command and tools! :party:
```
conda activate oas
cd c:\src\OpenAutoScope-v2
pip install -e .
```

> Congrats! `oas` is now installed!!! :party:
> The only remaining steps are uploading teensy code and writing down correct camera serial numbers before running the `oas`.

## (4) Arduino Software
> If the installation fails due to antivirus prevention, you might need to temporarily deactivate you antivirus for the installation. YET this is not recommended and proceed at your own risk!
- (4.1) Visit [Arduino Software IDE](https://www.arduino.cc/en/software/#ide) website and download the `Arduino IDE`. At the time of writing this guide, the downloaded file+version is `arduino-ide_2.3.6_Windows_64bit.exe`
- (4.2) Run the installation file `arduino-ide_2.3.6_Windows_64bit.exe` and follow the instructions and prompts
- (4.3) Let's add Teensy board management support by adding the indexing info
  - (4.3.1) Open 'File -> Preferences' window and find 'Additional boards manager URLs' section
  - (4.3.2) Add this line to `Additional boards manager URLs` section
  ```
  https://www.pjrc.com/teensy/package_teensy_index.json
  ```
  - (4.3.3) Press 'Ok' and go back to main IDE window
- (4.4) Open 'Tools -> Board -> Boards Manager' from top bar, then a side bar from left appears that allows searhing board names
  - (4.4.1) Search 'Teensy'
  - (4.4.2) Look for and install the package "Teensy by Paul Stoffregen"
- (4.5) Open the arduino code provided in the `OpenAutoScope-v2` folder, from 'File -> Open' in the following path
```
C:\src\OpenAutoScope-v2\openautoscopev2\teensy\TeensyController\TeensyController.ino
```
- (4.6) Go to 'Tools -> Board' and from 'Teensy' section, select the appropriate Teensy board model. In our case it is 'Teensy LC', it could be 'Teensy 4.0' in your case.
```
Tools -> Board -> Teensy (for Arduino 2.0.4 or later) -> Teensy LC
```
- (4.7) Then select the appropriate port that corresponds to the teensy board, and make sure it is automatically detected/named as a "Teensy" port. The port number "COM4" can be different in you case!
```
Tools -> Port -> teensy ports -> COM4 (Teensy LC)
```
- (4.8) Write down the port number for the teensy board since you will need it later: e.g. in this case `COM4`
- (4.9) Now it's time to upload the code to the teensy controller to run it. Make sure you wait till you see a notification (bottom right), that says "Uploading completed"
```
Sketch -> Upload
```
> And indicator of code successfully uploaded is the blue/orange LED turining on, then off during this process (if the driver knob is set to non-zero).

## (5) Running the OAS
Here are the steps you need to do to run `oas` software
- (5.0) (Only once) configure the `c:\src\configs.json` file with proper teensy board "COM" number and camera serial numbers
  - change the "COM3" in front of "teensy_usb_port" to  whatever `COM` value you've found in the section (4.8) to upload the code, e.g. "COM4"
  - set the appropriate serial numbers for behavior and gcamp cameras by reading them on the camera label or using "SpinView" software
- (5.1) To run `oas`, open a CMD in windows and run the following line by line
```
conda activate oas
oas
```

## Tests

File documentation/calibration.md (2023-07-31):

# Calibration and Parameter settings

If you've reached this point, we assume that you have completed the hardware assembly, installed the software, familiarized yourself with the parameter file, 
read about how to utilize the GUI or Xbox controller for stage movement.

### Power Supply

To ensure functionality, three devices must be connected to power supplies. The PCB board and two LED controllers require individual power sources. 
For the PCB board, use the 5A power supply. As for the LED controllers, the power adapter provided by Thorlabs is suitable for their operation.

### LED Contoller

To determine the maximum allowed current for the 470nm LED and the 595nm LED, refer to their respective specification sheets. These documents provide information
regarding the recommended operating conditions. Additionally, on the back of each LED controller, you will find a potentiometer that enables you to set the maximum output current.
To adjust the current, use a small flat screwdriver to turn the potentiometer. Carefully rotate it until you reach the desired maximum output current level for each LED. 

<p align="center">
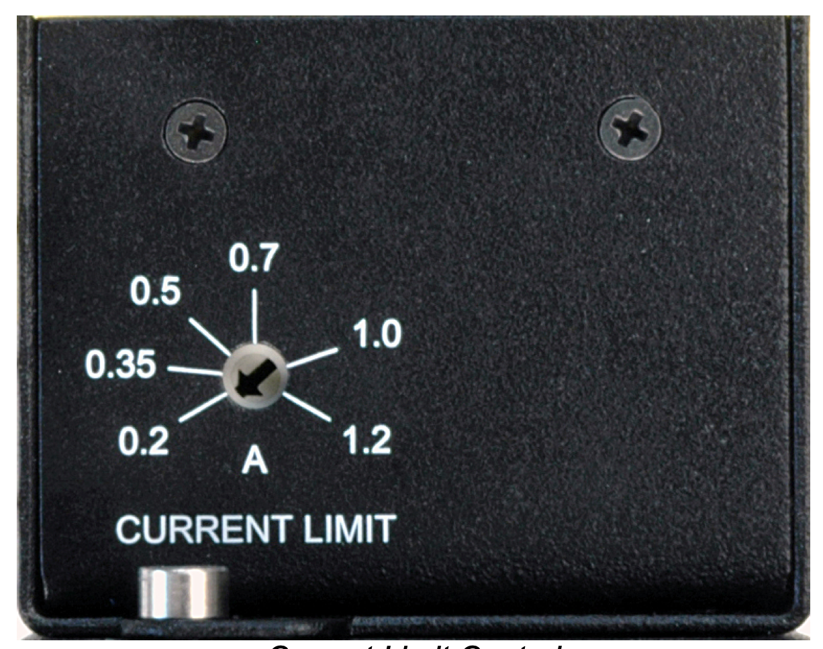
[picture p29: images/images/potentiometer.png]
  
</p>

Once you have properly adjusted the max current for the LEDs and ensured that the LED controllers are connected to their respective power adapters, the next step is to set
the mode to 'TRIG.' This mode allows you to use the software to turn the LED on/off. Use the knob to set the power.

For this, follow these steps using the top panel of the LED controller:  
  1- Adjust the mode setting to 'TRIG.'  
  2- Turn the knob clockwise until you hear a click. This click indicates that the circuit is activated and the current can flow using the LED toggle buttons on the software.

<p align="center">
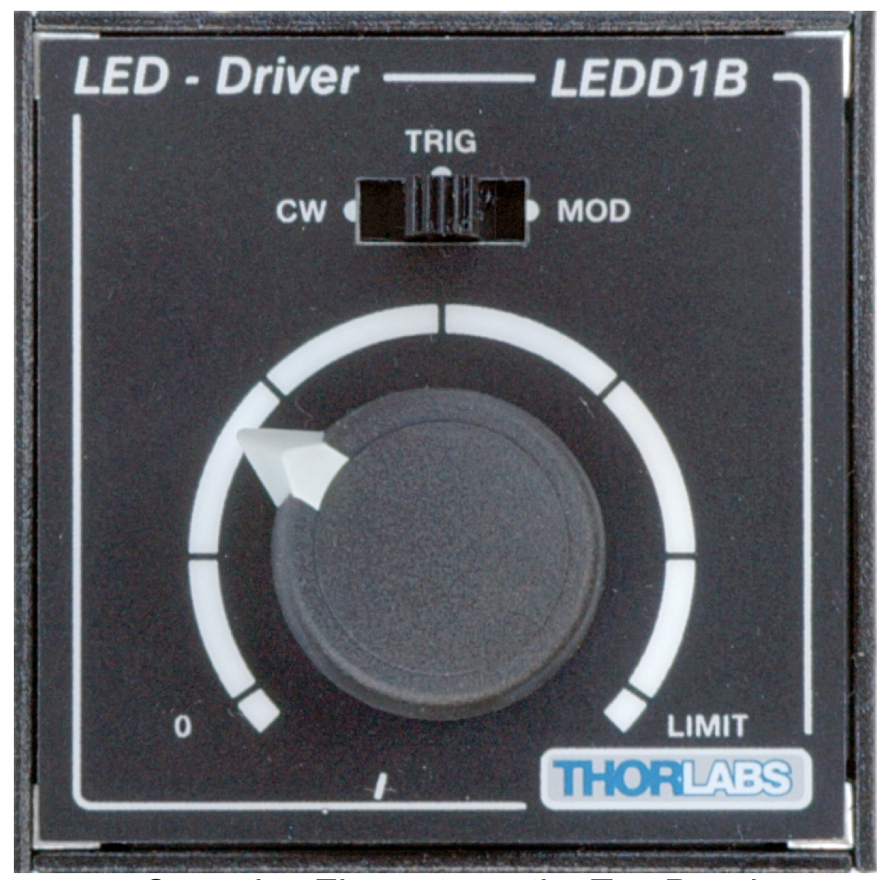
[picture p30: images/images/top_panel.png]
  
</p>

### Stepper Motor Drivers

To ensure the proper functioning of the stepper motor drivers and prevent overheating, it is necessary to set the maximum output current using the potentiometers located on them. For this follow these steps:  
It is important to note that running these on high current can burn the part after a few seconds. This has to be done for all 3 motors as fast as possible.

1- Run the system to engage the stepper motors (open a command prompt and enter `activate oas && oas`)  
2- Use a voltmeter to measure the voltage between the specified pins on the stepper motor drivers.  
3- With the voltmeter connected, locate the potentiometer on each stepper motor driver and use a small flat screwdriver to adjust it. Gradually turn the potentiometer until the voltage reading reaches 0.2V.  

An alternative method that can make the voltage measurement easier is to connect one terminal of the voltmeter to the flat screwdriver and insert it inside the potentiometer.

<p align="center">
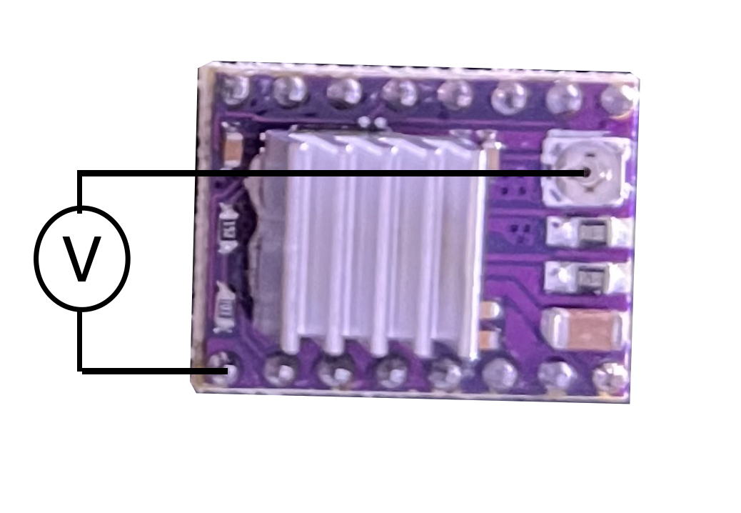
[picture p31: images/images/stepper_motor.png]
  
</p>

### Teensy Port

During the [installation](installation.md) process (Arduino Software section), you utilized the Arduino app to identify the port to which the Teensy board is connected. It is crucial to make a note of this port and enter it correctly in the [configuration file](../configs.json). This step ensures proper communication between the software and the Teensy board, enabling seamless functionality and data transfer.

### Blackout Cover

To ensure that the lighting conditions in the room where the system is located do not interfere with the imaging sessions, follow these steps:  

1- Stack two 0.5-inch optical posts, one measuring 10 inches and the other 6 inches in height to make four longer posts.  
2- Use 1/4-20 set screws to securely mount the four longer posts on the corners of the breadboard.  
3- Cover the entire system with black nylon fabric. This fabric acts as a blackout material, minimizing external light interference during imaging sessions.  

### Cameras

To perform the three calibration steps for the image plane, follow these instructions:  

1- Go to the [configuration file](../configs.json) in the repository, open it, and change the parameter 'q' to 0.  
2- Run the system by opening a command prompt and typing `activate oas && oas`.  
3- Turn on the IR LED and adjust the stage to focus the behavioral camera on the stacked calibration slide.  
4- Turn on the 470nm LED, using a low laser power and/or low exposure time to minimize potential saturation.  
5- Rotate the precision zoom housing to ensure that the GCaMP camera is also focused on the stacked calibration slide. If necessary, make adjustments to the position of both cameras.  
Note that the precision zoom housings were initially set to their mid-travel range during assembly.  
6- Utilize the CUP1 parts to rotate each camera and ensure that the images in both channels have the same orientation. The CUP1 allows you to rotate the camera without changing its position.

<p align="center">
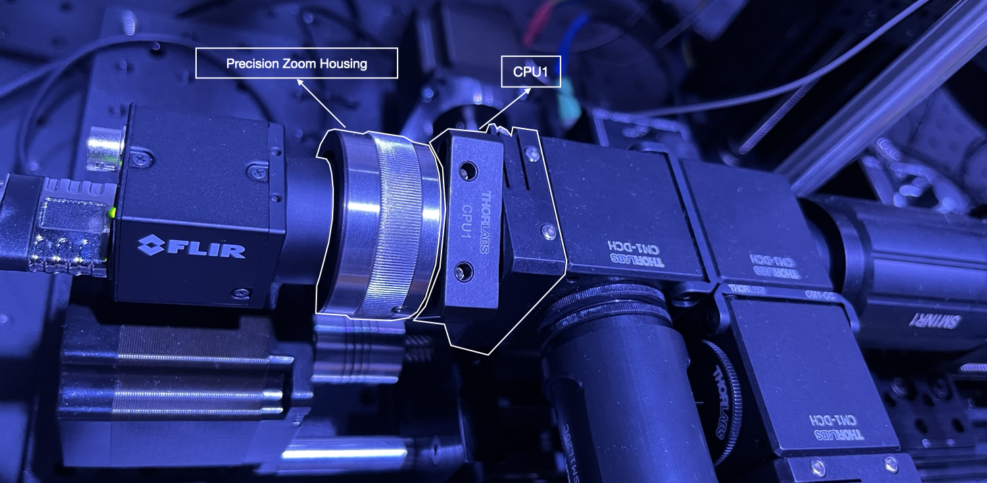
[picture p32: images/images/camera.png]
  
</p>

7- Use the offset buttons on the GUI to adjust the offset values for both the x and y axes for each camera. Fine-tune these values to achieve perfect alignment and ensure that the images are precisely aligned.  
8- Record the final offset values that resulted in perfect alignment in the [configuration file](../configs.json) and change the parameter 'q' to 0.7 (or any other desired value)  

Ther fisrt image shows the ovelay image before adjusting the offset values and the second image is after the adjustment.  

<p align="center">
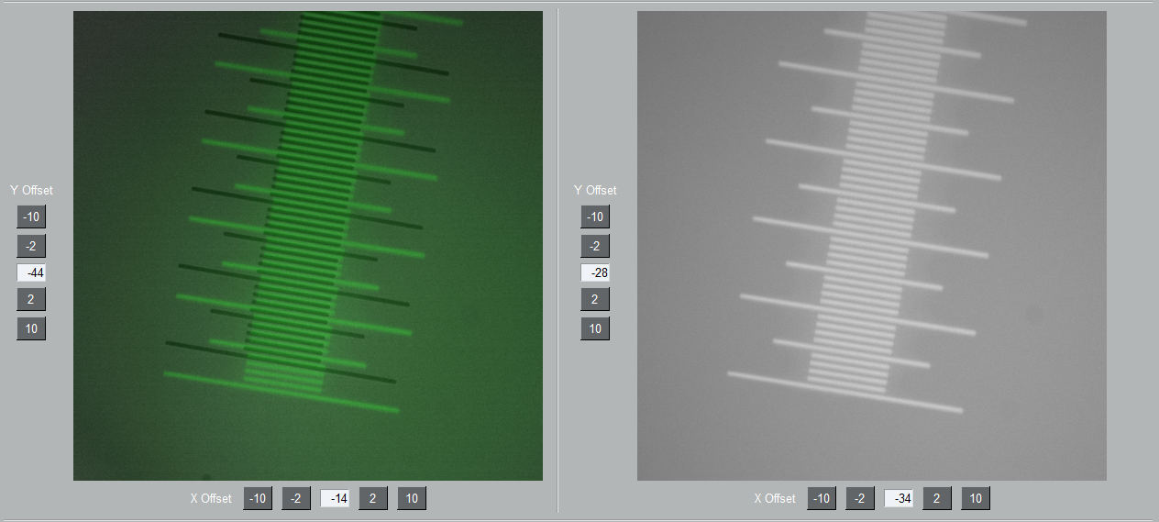
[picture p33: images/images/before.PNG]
  
</p>
<p align="center">
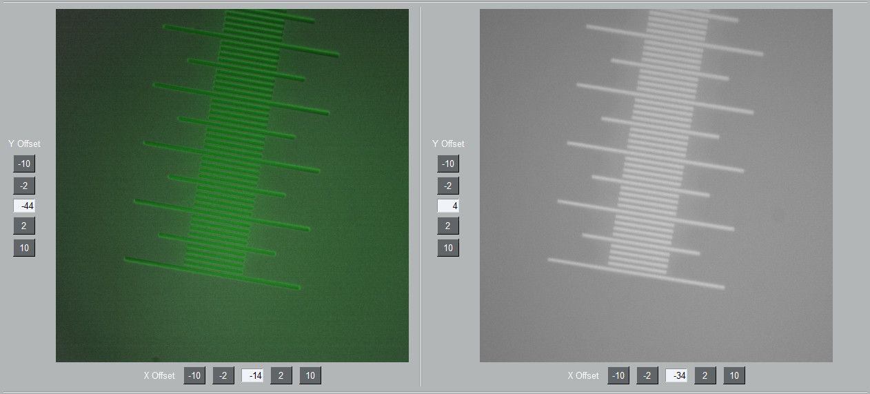
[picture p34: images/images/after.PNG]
  
</p>

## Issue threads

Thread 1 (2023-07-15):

Software crashes if the LED values are deleted using backspace button

mtorkashvand, 2023-07-15:
Reproduce:
Turn on the 470nm LED, to change the power percentage, delete the current value using backspace button

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

mtorkashvand, 2023-07-16:
When does `add_state` get called?
Is it when you press 'Enter'?

the reason I am asking this question is because I think the following is a common way to set some parameter:

- the laser intensity has some value (double-digit like 15%)
- user wants to change that to another value, say 25%
- user uses `backspace` twice, once to remove 5 and the second time to remove 1
- user inputs 2 followed by 5
- user presses 'Enter'

if `add_state` is called whenever a changes happens then in this case, the power does not go from 15 to 25 (which is what user wants). first it changes from 15 % to 1% then it changes from 1% to whatever the lower bound is then it changes from the lower bound to 2% and finally from 2% to 25% which is not what the user intended.

So I was thinking the fix for this is to make sure it only updates the value if 'Enter' is pressed.

SinRas, 2023-07-16:
@mtorkashvand
The element [Return Handler](https://github.com/venkatachalamlab/OpenAutoScope-v2/blob/main/openautoscopev2/ui/elements.py#L81-L107) is responsible for detection of 'return/enter key press'.
The element [InputAutoselect](https://github.com/venkatachalamlab/OpenAutoScope-v2/blob/main/openautoscopev2/ui/elements.py#L109-L170) is a regular input that only apply's its value, when 'return/enter key press' is done.
We checked it and it was working as intended described below:
> Changes only take effect after pressing 'return' key. Not while typing.

If that's now how it's working, can you give me specific element names to check them?

Closed 2023-07-15.

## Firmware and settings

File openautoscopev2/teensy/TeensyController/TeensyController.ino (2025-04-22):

// Copyright 2023
// Author: Sina Rasouli, Mahdi Torkashvand

#include <AccelStepper.h>

#define P_ENABLE 6
#define P_RESTSLEEP 2
#define P_M0 5
#define P_M1 4
#define P_M2 3
#define P_DIR_X 0
#define P_STP_X 1
#define P_DIR_Y 7
#define P_STP_Y 8
#define P_DIR_Z 9
#define P_STP_Z 10
#define P_LED_BEHAVIOR 21
#define P_LED_GCAMP 17
#define P_LED_OPTOGENETIC 16

#define DEFAULT_STEPMODE 7
#define STEPPER_MAXSPEED_X 1024.0
#define STEPPER_MAXSPEED_Y 1024.0
#define STEPPER_MAXSPEED_Z 1024.0
#define STEPPER_ACCELERATION_X 10000.0
#define STEPPER_ACCELERATION_Y 10000.0
#define STEPPER_ACCELERATION_Z 10000.0

#define SIZE_COMMAND_BUFFER 32

AccelStepper stepperX(AccelStepper::DRIVER, P_STP_X, P_DIR_X);
AccelStepper stepperY(AccelStepper::DRIVER, P_STP_Y, P_DIR_Y);
AccelStepper stepperZ(AccelStepper::DRIVER, P_STP_Z, P_DIR_Z);

long x, y, z;
long xlimp=45000.0; 
long ylimp=45000.0;
long zlimp=0.0; // Original value: 0.0
long xlimn=-45000.0;
long ylimn=-45000.0;
long zlimn=-90000.0;  // Original value: -30000.0
long vx, vy, vz;
char *comBuf;
int nChar;

void setStepMode(int mode) {
  int res = mode >= 7 ? 7 : mode;
  int m0 = res % 2;
  res /= 2;
  int m1 = res % 2;
  res /= 2;
  int m2 = res % 2;

  digitalWrite( P_M0, m0 );
  digitalWrite( P_M1, m1 );
  digitalWrite( P_M2, m2 );
}

void setup()
{
  Serial.begin(115200);
  Serial.setTimeout(100);

  comBuf = (char*) malloc(SIZE_COMMAND_BUFFER);
  nChar = 0;

  int ports [] = {
    P_ENABLE, P_RESTSLEEP,
    P_M0, P_M1, P_M2,
    P_DIR_X, P_STP_X,
    P_DIR_Y, P_STP_Y,
    P_DIR_Z, P_STP_Z,
    P_LED_BEHAVIOR,
    P_LED_GCAMP, P_LED_OPTOGENETIC
  };
  for (int port : ports) {
    pinMode(port, OUTPUT);
  }

  stepperX.setMaxSpeed(STEPPER_MAXSPEED_X);
  stepperY.setMaxSpeed(STEPPER_MAXSPEED_Y);
  stepperZ.setMaxSpeed(STEPPER_MAXSPEED_Z);

  stepperX.setAcceleration(STEPPER_ACCELERATION_X);
  stepperY.setAcceleration(STEPPER_ACCELERATION_Y);
  stepperZ.setAcceleration(STEPPER_ACCELERATION_Z);

  stepperX.setSpeed(0.0);
  stepperY.setSpeed(0.0);
  stepperZ.setSpeed(0.0);

  setStepMode(DEFAULT_STEPMODE);
}

void loop()
{
  if ( Serial.available() > 0 )
  {
    nChar = Serial.readBytesUntil('\n', comBuf, SIZE_COMMAND_BUFFER);

    char cmd = comBuf[0];
    char subcmd = comBuf[1];
    if (cmd == 'l')
    {
      char state = comBuf[2];
      if ( subcmd == 'b' )
      {
        if ( state == '1' ) 
        {
          digitalWrite(P_LED_BEHAVIOR, HIGH);
        } 
        else if ( state == '0')
        {
          digitalWrite(P_LED_BEHAVIOR, LOW);
        }
      }
      else if ( subcmd == 'g' ) 
      {
        if ( state == '1' )
        {
          digitalWrite(P_LED_GCAMP, HIGH);
        }
        else if ( state == '0' )
        {
          digitalWrite(P_LED_GCAMP, LOW);
        }
      }
      else if ( subcmd == 'o' )
      {
        if ( state == '1' )
        {
          digitalWrite(P_LED_OPTOGENETIC, HIGH);
        }
        else if ( state == '0' )
        {
            digitalWrite(P_LED_OPTOGENETIC, LOW);
        }
      }
    }
    else if (cmd == 's')
    {
      if ( subcmd == 'n')
      {
        digitalWrite(P_ENABLE, LOW);
        digitalWrite(P_RESTSLEEP, HIGH);
        stepperX.setSpeed(0);
        stepperY.setSpeed(0);
        stepperZ.setSpeed(0);
        stepperX.setCurrentPosition(0);
        stepperY.setCurrentPosition(0);
        stepperZ.setCurrentPosition(0);
      }
      else if ( subcmd == 'f' )
      {
        stepperX.setSpeed(512);
        stepperY.setSpeed(512);
        stepperZ.setSpeed(512);
        if (xlimp <= 0)
        {
          stepperX.runToNewPosition(xlimp);
        }
        else if (xlimn >= 0)
        {
          stepperX.runToNewPosition(xlimn);
        }
        else 
        {
          stepperX.runToNewPosition(0);
        }
        if (ylimp <= 0)
        {
          stepperY.runToNewPosition(ylimp);
        }
        else if (ylimn >= 0)
        {
          stepperY.runToNewPosition(ylimn);
        }
        else 
        {
          stepperY.runToNewPosition(0);
        }
        if (zlimp <= 0)
        {
          stepperZ.runToNewPosition(zlimp);
        }
        else if (zlimn >= 0)
        {
          stepperZ.runToNewPosition(zlimn);
        }
        else 
        {
          stepperZ.runToNewPosition(0);
        }
        stepperX.setSpeed(0);
        stepperY.setSpeed(0);
        stepperZ.setSpeed(0);
        digitalWrite(P_ENABLE, HIGH);
        digitalWrite(P_RESTSLEEP, LOW);
      }
      else if ( subcmd == 'x')
      {
        stepperX.setSpeed(atof(comBuf + 2));
      }
      else if ( subcmd == 'y')
      {
        stepperY.setSpeed(atof(comBuf + 2));
      }
      else if ( subcmd == 'z')
      {
        stepperZ.setSpeed(atof(comBuf + 2));
      }
    }
    else if ( cmd == 'g' )
    {
      if ( subcmd == 'p')
      {
        // This is only to return the current position.
      }
    }
    else if ( cmd == 'm')
    {
      char dir = comBuf[2];
      if ( subcmd == 'x' )
      {
        if ( dir == 'p')
        {
          xlimp=stepperX.currentPosition();
        }
        else if ( dir == 'n')
        {
          xlimn=stepperX.currentPosition();
        }
      }
      else if ( subcmd == 'y' )
      {
        if ( dir == 'p')
        {
          ylimp=stepperY.currentPosition();
        }
        else if ( dir == 'n')
        {
          ylimn=stepperY.currentPosition();
        }
      }
      else if ( subcmd == 'z')
      {
        if ( dir == 'p')
        {
          zlimp=stepperZ.currentPosition();
        }
        else if ( dir == 'n')
        {
          zlimn=stepperZ.currentPosition();
        }
      }
    }

    x=stepperX.currentPosition();
    y=stepperY.currentPosition();
    z=stepperZ.currentPosition();
    vx=stepperX.speed();
    vy=stepperY.speed();
    vz=stepperZ.speed();
    Serial.print(x);
    Serial.print(" ");
    Serial.print(y);
    Serial.print(" ");
    Serial.print(z);
    Serial.print(" ");
    Serial.print(vx);
    Serial.print(" ");
    Serial.print(vy);
    Serial.print(" ");
    Serial.print(vz);
    Serial.print("\n");
    Serial.send_now();
  }

  x = stepperX.currentPosition();
  y = stepperY.currentPosition();
  z = stepperZ.currentPosition();

   if ( x > xlimp && vx > 0 )
   {
     stepperX.setSpeed(0);
   }
   else if ( x < xlimn && vx < 0 )
   {
     stepperX.setSpeed(0);
   }

   if ( y > ylimp && vy > 0 )
   {
     stepperY.setSpeed(0);
   }
   else if ( y < ylimn && vy < 0 )
   {
     stepperY.setSpeed(0);
   }

   if( z > zlimp && vz > 0 )
   {
     stepperZ.setSpeed(0);
   }
   else if( z < zlimn && vz < 0 )
   {
     stepperZ.setSpeed(0);
   }

  stepperX.runSpeed();
  stepperY.runSpeed();
  stepperZ.runSpeed();
}

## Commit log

2023-07-12 add initial version of software
    [Drill_NPTH_Through.DRL, Drill_PTH_Through.DRL, Drill_PTH_Through_Via.DRL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]
2023-07-15 Change the default constants for the P term in PID controller
2023-07-19 Change GFP and Opto LED to only toggle on and off
2023-07-19 change LED GFP to toggle
2023-07-28 Upload the Woods hole version of the software
    [Drill_NPTH_Through.DRL, Drill_PTH_Through.DRL, Drill_PTH_Through_Via.DRL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]
2024-06-13 add full framerate writing when LEDs are on
2024-06-13 add write every n frames input field
2025-04-20 many changes: timestamp from flircamera, experiments module, separate tracking and focus models, camera GAIN settings in the code
2025-04-21 change proxy socket type to PAIR for newer version compatibility
2025-04-28 add PID handling of NaN/None
2026-09-22 Add morphology and pumping showcase figures
